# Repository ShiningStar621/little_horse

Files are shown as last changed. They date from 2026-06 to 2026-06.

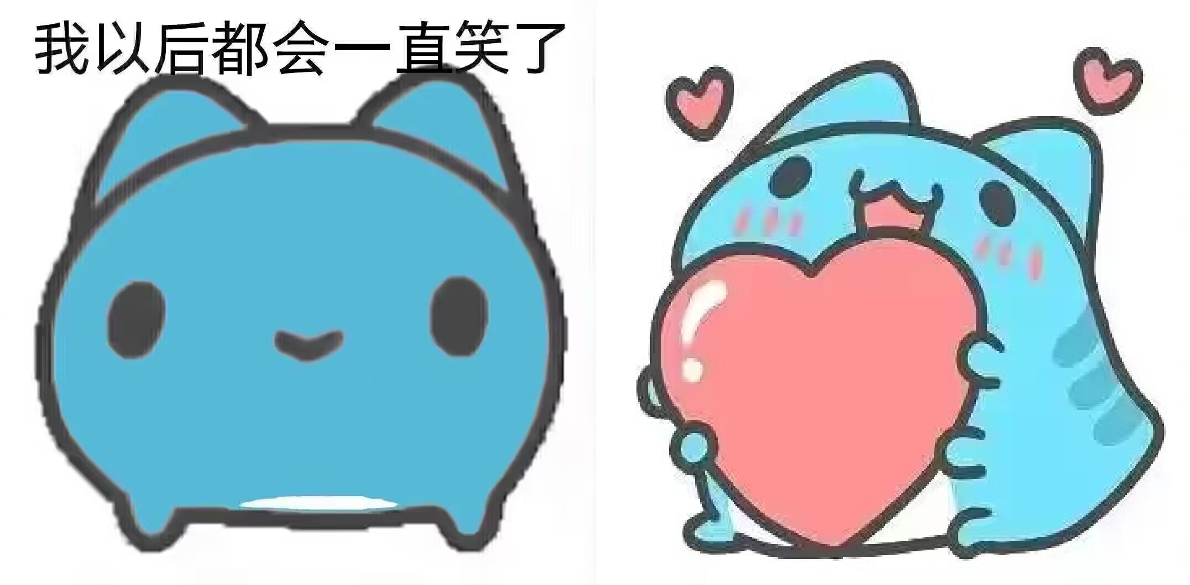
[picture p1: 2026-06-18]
images/原图/EFB1394C15E5EA0CE02DC21B37489DED.jpg

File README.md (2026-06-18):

# 地猛星 (Di Meng Xing) — MSPM0G3507 四足语音机器人

> 哈尔滨工业大学（深圳）电子工艺实习项目  |  2026年4月–6月

基于 TI MSPM0G3507 的四足机器人，集成离线语音识别、OLED 状态显示、MP3 音频
反馈和 4 路舵机步态控制。支持 9 条语音口令非接触控制，5 种步态模式（前进、后退、
左转、右转、跳舞）。

---

## 硬件架构

| 模块 | 型号 | 接口 | 说明 |
|---|---|---|---|
| MCU | MSPM0G3507 (Cortex-M0+, 32MHz) | — | TI LaunchPad 开发板 |
| 语音识别 | CI1302 | 软件 I2C (PB2/PB3) | 离线非特定人，9条口令 |
| 显示屏 | SH1106 OLED 1.3" 128×64 | 软件 SPI (PA12/13/16/17/22) | 单色，页寻址 |
| MP3 播放 | WT2003H4 M09 | UART1 (PA8, 115200) | TF卡，3W功放 |
| 舵机 ×4 | SG90 | 独立 PWM 50Hz | 外部 5V/3A 供电 |
| 3D 外壳 | PLA 打印 | — | 立式屏幕支架+紧凑布局 |

## 引脚映射

| 引脚 | 功能 | 引脚 | 功能 |
|---|---|---|---|
| PA0 | 舵机 FR (前右) | PA15 | 舵机 FL (前左) |
| PA8 | MP3 UART TX | PA16 | OLED DC |
| PA9 | MP3 UART RX | PA17 | OLED RES |
| PA10 | 调试 UART TX | PA21 | 舵机 RL (后左) |
| PA11 | 调试 UART RX | PA22 | OLED CS |
| PA12 | OLED SCL | PA23 | 舵机 RR (后右) |
| PA13 | OLED SDA | PB2 | CI1302 SCL |
| PA14 | 板载 LED | PB3 | CI1302 SDA |

## 语音命令

| 口令 | 命令ID | 步态 | 口令 | 命令ID | 步态 |
|---|---|---|---|---|---|
| 前进 | 0x01 | 对角小跑 | 行走 | 0x06 | 归中站立 |
| 后退 | 0x02 | 后退小跑 | 停止 | 0x07 | 卧倒休眠 |
| 左转 | 0x03 | 原地左旋 | 跳舞 | 0x08 | 四相波浪 |
| 右转 | 0x04 | 原地右旋 | 唱歌 | 0x09 | 仅MP3 |
| 坐下 | 0x05 | 坐下姿态 | | | |

## 目录结构

```
├── README.md                  # 本文件
├── docs/                      # 文档
│   ├── 地猛星机器人发布说明书.md / .docx
│   ├── 硬件安装说明书.md
│   └── 屏幕硬件图.pdf
├── firmware/                  # 源代码
│   ├── empty.c                # 主程序 (~740行)
│   ├── board.c / board.h      # 板级初始化+延时
│   ├── ti_msp_dl_config.c/.h  # SysConfig 生成
│   ├── empty.syscfg           # SysConfig 工程
│   ├── LCD/                   # OLED 驱动
│   │   ├── lcd_init.c/.h      # SH1106 底层
│   │   ├── lcd.c/.h           # 上层绘图
│   │   ├── lcdfont.h          # ASCII 字库
│   │   └── img_*.h (×11)      # Image2Lcd 图片
│   └── keil/                  # Keil 工程
├── hardware/                  # 硬件设计
│   ├── pcb文件.epro           # 立创EDA PCB
│   └── 屏幕尺寸.png
├── model/                     # 3D 打印模型 (SolidWorks)
├── voice-module/              # CI1302 语音模块
│   ├── 固件/
│   ├── 烧录工具/
│   └── 文档
├── mp3-module/                # WT2003H4 MP3 模块
├── images/                    # OLED 图片资源
│   ├── 原图/                  # BMP/PNG 原图
│   └── 取模数组/              # Image2Lcd 生成的 .c
└── tools/                     # 工具
    └── Image2Lcd/             # 图片取模工具
```

## 编译与烧录

- **编译器**: ARMCLANG V6.21 (Keil MDK)
- **工程文件**: `firmware/keil/empty_LP_MSPM0G3507_nortos_keil.uvprojx`
- **Include 路径**: `..` (firmware), `../../..` (SDK根), `../LCD`
- **预编译**: 需禁用 Keil 预编译步骤（SysConfig 权限问题）
- **烧录**: Keil F8 或使用 TI Uniflash

## 注意事项

1. **舵机必须独立供电**（外部 5V/3A），绝不能接板卡 5V 排针
2. SH1106 与 SSD1306 驱动不兼容——列偏移 +2、页寻址、电荷泵 0xAD
3. CI1302 识别结果 ID 为 0x01-0x09（播报编号为 0x81-0x89，两者不同）
4. OLED_Init() 必须在 Servo_Init() 之前（避免 GPIO 干扰 PWM）
5. MP3 模块 UART 需手动设 115200（SysConfig 默认 9600）

## 已知问题

- [ ] 前进/后退步态需上机调参以获得地面推力
- [ ] 跳舞/左转/右转步态未经实物验证
- [ ] img_sleep/dance/sing.h 为全黑占位图，待替换
- [ ] SMOOTH_STEP=30 偏大，建议降至 3~10

## 许可

MIT License

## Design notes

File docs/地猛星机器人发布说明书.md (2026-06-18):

# 地猛星 MSPM0G3507 四足机器人 — 发布说明书

> **版本**: 2026-06-16 | **作者**: 地猛星项目组 | **MCU**: MSPM0G3507 (Cortex-M0+, 32MHz)

---

## 一、项目概览

地猛星是一台基于 TI MSPM0G3507 的四足机器人，集成语音识别、OLED 显示、MP3 音频和舵机步态控制。

**核心功能**:
- 语音命令识别（CI1302 离线语音模块，无需联网）
- 1.3 寸 OLED 实时状态显示
- WT2003H4 MP3 模块音频反馈
- 4 路独立 PWM 舵机，非阻塞步态引擎
- 8 种机器人行为：前进/后退/左转/右转/坐下/站立/停止/跳舞/唱歌

---

## 二、硬件架构

### 2.1 MCU — MSPM0G3507

| 项目 | 参数 |
|---|---|
| 内核 | ARM Cortex-M0+ |
| 主频 | 32 MHz |
| Flash | 128 KB |
| SRAM | 32 KB |
| 开发板 | LP-MSPM0G3507 |
| SDK 版本 | mspm0_sdk_1_30_00_03 |
| 编译工具 | Keil MDK V6.21 (ARMCLANG) |

### 2.2 外设模块

| 模块 | 型号 | 通信接口 | 供电 |
|---|---|---|---|
| 语音识别 | CI1302 | I2C (软件模拟, PB2/PB3) | 3.3V |
| OLED 屏幕 | 1.3寸 SH1106 单色 128×64 | SPI (软件模拟) | 3.3V |
| MP3 播放 | WT2003H4 M09 | UART1 (PA8/PA9, 115200) | 5V 外部 |
| 舵机 ×4 | SG90 兼容 | PWM 独立 4 通道 | 5V 外部独立供电 |
| 调试串口 | USB-TTL | UART0 (PA10/PA11, 115200) | USB |

### 2.3 完整引脚映射

| MSPM0 引脚 | 连接对象 | 功能 | 备注 |
|---|---|---|---|
| **PA0** | 舵机 FR | PWM_2 (TIMA0 CCP0) | 前右腿 |
| **PA8** | MP3 模块 RX | UART1 TX | MCU → MP3 |
| **PA9** | MP3 模块 TX | UART1 RX | MP3 → MCU (可选不接) |
| **PA10** | USB-TTL RX | UART0 TX | 调试 printf |
| **PA11** | USB-TTL TX | UART0 RX | 调试输入 |
| **PA12** | OLED D0 | SPI SCL (软件) | 时钟 |
| **PA13** | OLED D1 | SPI SDA (软件) | 数据 |
| **PA14** | 板载 LED | GPIO 输出 | 状态指示 (低电平亮) |
| **PA15** | 舵机 FL | PWM_1 (TIMA1 CCP0) | 前左腿 |
| **PA16** | OLED DC | GPIO 输出 | 命令/数据选择 |
| **PA17** | OLED RES | GPIO 输出 | 复位 |
| **PA21** | 舵机 RL | PWM_3 (TIMG6 CCP0) | 后左腿 |
| **PA22** | OLED CS | GPIO 输出 | 片选 |
| **PA23** | 舵机 RR | PWM_4 (TIMG0 CCP0) | 后右腿 |
| **PB2** | CI1302 SCL | I2C SCL (软件) | 语音模块时钟 |
| **PB3** | CI1302 SDA | I2C SDA (软件) | 语音模块数据 |

### 2.4 电源分配

```
外部 5V 电源 (独立供电，≥2A)
    ├── 舵机 VCC ×4  ⚠️ 必须独立供电
    ├── MP3 模块 VCC
    └── 【不要接板卡 5V 排针！会倒灌烧毁电源】

板卡 3.3V (USB 或板载 LDO)
    ├── OLED VCC
    └── CI1302 VCC

所有模块 GND 必须共地
```

> ⚠️ **舵机必须独立供电**。4 个舵机同时动作峰值电流可达 2-3A，从板卡 5V 取电会导致电压跌落、屏幕掉电重启、MCU 复位等问题。

---

## 三、软件架构

### 3.1 源码结构

```
driverlib/empty/
├── empty.c                    # 【主程序】单文件, ~720行
├── board.c / board.h          # 板级初始化 + delay_us/ms
├── ti_msp_dl_config.c/.h      # SysConfig 自动生成 (时钟/引脚/PWM/UART)
├── empty.syscfg               # SysConfig 工程配置
├── LCD/
│   ├── lcd_init.c/.h          # OLED 驱动 (SH1106 软件 SPI + 帧缓冲)
│   ├── lcd.c/.h               # 上层绘图 (字符/线条/图片)
│   ├── lcdfont.h              # ASCII 字库 (12/16pt)
│   ├── img_idle.h             # 待机图片 (128×64 单色)
│   ├── img_go.h               # 前进图片
│   ├── img_back.h             # 后退图片
│   ├── img_left.h             # 左转图片
│   ├── img_right.h            # 右转图片
│   ├── img_sit.h              # 坐下图片
│   ├── img_walk.h             # 行走图片
│   ├── img_stop.h             # 停止图片
│   ├── img_sleep.h            # 休眠图片
│   ├── img_dance.h            # 跳舞图片
│   └── img_sing.h             # 唱歌图片
└── keil/                      # Keil 工程文件
```

### 3.2 程序执行流程

```
上电
  │
  ├─ board_init()              # 时钟/SysTick/GPIO/UART 初始化
  ├─ MP3_SetVol(25)            # MP3 模块音量初始化
  ├─ MP3_Stop()                # 确保 MP3 停止
  ├─ OLED_Init()               # SH1106 初始化 + 清屏
  ├─ Servo_Init()              # 4 舵机归中 (CCR=750)
  ├─ 开机自检                  # 舵机微动确认 PWM 正常
  └─ 进入主循环 ──────────────┐
        │                      │
        ├─ CI1302_Recognition() # 轮询语音识别结果 (I2C)
        ├─ 如有新命令 → HandleCommand()
        │   ├─ 更新 OLED 图片+文字
        │   ├─ 触发 MP3 播放
        │   ├─ CI1302 语音播报
        │   └─ 设置舵机状态机 (g_state)
        │
        ├─ 非阻塞步态更新 (根据 g_state)
        │   ├─ STATE_WALK_FORWARD  → GAIT_FORWARD
        │   ├─ STATE_WALK_BACKWARD → GAIT_BACKWARD
        │   ├─ STATE_TURN_LEFT     → GAIT_TURN_LEFT
        │   ├─ STATE_TURN_RIGHT    → GAIT_TURN_RIGHT
        │   └─ STATE_DANCE         → GAIT_DANCE
        │
        └─ delay_ms(5) ──────────┘
```

### 3.3 系统状态机

| 状态 | 枚举值 | 触发命令 | 步态行为 |
|---|---|---|---|
| `STATE_IDLE` | 0 | 停止(0x07) | 不更新步态 |
| `STATE_WALK_FORWARD` | 1 | 前进(0x01)/行走(0x06) | 非阻塞前进步态 |
| `STATE_WALK_BACKWARD` | 2 | 后退(0x02) | 非阻塞后退步态 |
| `STATE_TURN_LEFT` | 3 | 左转(0x03) | 非阻塞原地左旋 |
| `STATE_TURN_RIGHT` | 4 | 右转(0x04) | 非阻塞原地右旋 |
| `STATE_SIT` | 5 | 坐下(0x05) | 阻塞: 坐下姿态 |
| `STATE_DANCE` | 6 | 跳舞(0x08) | 非阻塞跳舞步态 |

---

## 四、通信协议

### 4.1 CI1302 语音识别 (I2C)

| 项目 | 参数 |
|---|---|
| 接口 | 软件模拟 I2C (PB2=SCL, PB3=SDA) |
| 从机地址 | 0x34 (7-bit) |
| 识别结果寄存器 | 0x64 |
| 播报命令寄存器 | 0x6E |

**命令 ID 映射** (CI1302 出厂固化的语音词条):

| 语音口令 | 命令 ID | 功能 |
|---|---|---|
| "前进" | 0x01 | 向前走 |
| "后退" | 0x02 | 向后退 |
| "左转" | 0x03 | 原地左旋 |
| "右转" | 0x04 | 原地右旋 |
| "坐下" | 0x05 | 坐下姿态 |
| "行走" | 0x06 | 向前走 (同前进) |
| "停止" | 0x07 | 卧倒休眠 |
| "跳舞" | 0x08 | 跳舞步态 |
| "唱歌" | 0x09 | MP3 唱歌 |

**播报触发**:
```c
CI1302_Speak(CI1302_CMD, 0x81);     // CI1302 播放预存语音 0x81
CI1302_Speak(CI1302_ANNOUNCE, 0x01); // 开机播报
```

### 4.2 WT2003H4 MP3 (UART)

| 项目 | 参数 |
|---|---|
| 接口 | UART1 (PA8=TX, PA9=RX) |
| 波特率 | 115200 bps |
| 协议 | 二进制帧: `7E + 长度 + 命令 + 参数 + 校验和 + EF` |

**常用命令**:
```c
MP3_Play(n)   // 播放第 n 首 (索引模式: 0xA0 + 2字节索引)
MP3_Stop()    // 停止播放 (0xAB)
MP3_SetVol(v) // 设置音量 0-31 (0xAE)
```

**波特率配置** (UART1 时钟 4MHz → 115200):
```c
DL_UART_Main_setBaudRateDivisor(UART_1_INST, 2, 11);  // DIV=2, MOD=11
```

### 4.3 SH1106 OLED (SPI)

| 项目 | 参数 |
|---|---|
| 分辨率 | 128×64 单色 |
| 接口 | 软件 SPI (PA12=SCL, PA13=SDA) |
| 控制引脚 | PA17=RES, PA16=DC, PA22=CS |
| 缓冲 | OLED_GRAM[128][8] (1024 字节) |
| 寻址 | 页寻址模式 (SH1106 不支持水平寻址) |

**图片格式**: Image2Lcd 取模, 水平扫描, 单色, 6 字节头 `[scan][bpp][w_lo][w_hi][h_lo][h_hi]`

---

## 五、舵机系统

### 5.1 PWM 配置

| 参数 | 值 | 说明 |
|---|-----|---|
| PWM 频率 | 50 Hz | 标准舵机频率 |
| 定时器时钟 | 500 kHz | 预分频后 |
| PWM 周期 (ARR) | 10000 | 20ms 周期 |
| CCR 范围 | 250 ~ 1250 | 0.5ms ~ 2.5ms 脉宽 |
| 中立位 CCR | 750 | 1.5ms 脉宽 = 90° |
| CCR ↔ 角度 | `CCR = 250 + angle × 1000 / 180` | 线性映射 |

### 5.2 舵机映射与安装方向

| 通道 | 腿 | PWM 实例 | MCU 引脚 | 安装方向 | g_legInv |
|---|-----|---|---|---|---|
| ch0 | FL 前左 | PWM_1 (TIMA1) | PA15 | 齿轮朝前 (正常) | 0 |
| ch1 | FR 前右 | PWM_2 (TIMA0) | PA0 | 齿轮朝前 (正常) | 1 |
| ch2 | RL 后左 | PWM_3 (TIMG6) | PA21 | 齿轮朝后 (反装) | 0 |
| ch3 | RR 后右 | PWM_4 (TIMG0) | PA23 | 齿轮朝后 (反装) | 1 |

**反相逻辑** (`g_legInv`):
- `inv=0` (正常): `CCR = v` — 直接使用步态曲线值
- `inv=1` (反相): `CCR = 1500 - v` — 绕中立位 750 镜像

> **为什么需要反相**: FR (前右) 和 RR (后右) 的舵机齿轮朝向与其他腿不同，相同 CCR 值会导致物理运动方向相反。反相后四条腿的物理运动方向统一。

### 5.3 特殊姿态

| 姿态 | FL (ch0) | FR (ch1) | RL (ch2) | RR (ch3) |
|---|---|---|---|---|
| 中立 (归中) | 750 | 750 | 750 | 750 |
| 坐下 | 750 | 750 | 1250 | 250 |
| 卧倒休眠 | 250 | 1250 | 1250 | 250 |

---

## 六、步态引擎

### 6.1 核心参数

```c
#define CYCLE_STEPS     100    // 周期步数 (100步 × 5ms = 500ms/周期)
#define CYCLE_DELAY_MS  5      // 每步延时
#define SMOOTH_STEP     30     // 每步 CCR 逼近量 (越大响应越快)
#define LAG_STEPS       (CYCLE_STEPS / 2)  // 对角腿相位差 (50步 = 半周期)
```

### 6.2 步态曲线

**前进曲线** `Gait_ForwardCCR(t)`:
- 0~9 步 (10%): 快前摆 — CCR 1050→450 (向前快速摆动)
- 10~99 步 (90%): 慢后推 — CCR 450→990 (向后慢速蹬地)

**后退曲线** `Gait_BackwardCCR(t)`:
- 0~9 步 (10%): 快后摆 — CCR 450→1050
- 10~99 步 (90%): 慢前推 — CCR 1050→510

> **设计原理**: 不对称占空比 (10% 摆动 + 90% 蹬地) 模拟生物步态。快速前摆减少空气阻力时间，慢速蹬地提供推进力。

### 6.3 步态模式

| 步态 | 对角配对 | 描述 |
|---|---|---|
| **前进** | FL+RR 领先 / FR+RL 滞后 | 对角小跑 (trot)，对角线两条腿同步 |
| **后退** | FL+RR 领先 / FR+RL 滞后 | 后退对角小跑 |
| **左转** | FL 后退+FR 前进 / RL 后退+RR 前进 | 右侧前进+左侧后退 = 原地逆时针旋转 |
| **右转** | FL 前进+FR 后退 / RL 前进+RR 后退 | 左侧前进+右侧后退 = 原地顺时针旋转 |
| **跳舞** | FL→FR→RL→RR 依次 1/4 周期 | 四相波浪传播，前后腿反相摇摆 |

### 6.4 平滑逼近算法

所有非阻塞步态使用相同的平滑插值:
```c
if (cur < target) cur += SMOOTH_STEP;  // 逐步接近目标
if (cur > target) cur -= SMOOTH_STEP;
```
这避免了瞬时 CCR 跳变导致的舵机剧烈抖动。

---

## 七、编译与烧录

### 7.1 Keil 工程

| 项目 | 路径/值 |
|---|---|
| 工程文件 | `keil/empty_LP_MSPM0G3507_nortos_keil.uvprojx` |
| 编译器 | ARMCLANG V6.21 |
| 优化等级 | -O0 (调试) |
| 代码大小 | ~14 KB Flash |
| 预编译步骤 | SysConfig 自动生成 `ti_msp_dl_config.c/.h` |

### 7.2 编译步骤

1. 打开 Keil 工程
2. 确认 `Options → C/C++ → Include Paths` 包含:
   - `..` (empty 目录)
   - `../../..` (SDK 根目录)
   - `../LCD`
3. Rebuild (F7)
4. 确认 0 Errors, 0 Warnings
5. 烧录 (F8)

### 7.3 首次上电检查

1. USB-TTL 接 PA10/PA11, 115200bps, 应看到:
   ```
   ================================
    DMX + CI1302 + OLED + Servo
   ================================
   [SERVO] 4ch ready
   [SYS] Ready.
   ```
2. OLED 显示待机画面
3. 舵机短暂微动后归中 (开机自检)
4. 说出语音口令测试各项功能

---

## 八、语音命令速查表

| 口令 | 命令ID | OLED 显示 | 舵机动作 | MP3 |
|---|---|---|---|-----|
| "前进" | 0x01 | 前进图标 | 连续前进 (对角小跑) | 第1首 |
| "后退" | 0x02 | 后退图标 | 连续后退 | 第2首 |
| "左转" | 0x03 | 左转图标 | 持续原地左旋 | 第3首 |
| "右转" | 0x04 | 右转图标 | 持续原地右旋 | 第4首 |
| "坐下" | 0x05 | 坐下图标 | 前腿归中 + 后腿前弯90° | - |
| "行走" | 0x06 | 行走图标 | 归中 (站立) | - |
| "停止" | 0x07 | 休眠图标 | 归中 → 200秒后卧倒休眠 | 第2首 |
| "跳舞" | 0x08 | 跳舞图标 | 连续四相波浪步态 | - |
| "唱歌" | 0x09 | 唱歌图标 | 不动 | 第1首 |

---

## 九、已知问题与解决记录

### 9.1 已解决

| 问题 | 原因 | 解决方案 |
|---|---|---|
| OLED 不亮 | 代码为 ST7789 TFT 驱动 | 重写 SH1106 初始化序列 + 页寻址 |
| OLED 显示花屏 | SH1106 不支持水平寻址 | 改用页寻址模式 `OLED_Refresh()` |
| 舵机不动 | CCR 范围错误 (0-3750) | 修正为 250-1250 (对应 0.5-2.5ms) |
| 代码超 32KB | Keil 评估版限制 | 禁用中文字库和大号 ASCII 字库 |
| 后腿运动方向错误 | 齿轮朝后安装 | 添加 `g_legInv[4]` 反相标志 |
| 跳舞时后腿不动 | `90 - Gait_ForwardCCR()` 负值溢出 | 改用四相波浪步态，正确使用 g_legInv |
| 闪屏/重复刷新 | 防抖逻辑缺失 | 添加 `g_lastDisplayedCmd` 缓存 |
| 编译报错 EPERM | syscfg.bat 权限问题 | 禁用预编译步骤 |
| 编译报错未声明 | 图片头文件缺失 | 创建 img_sleep/dance/sing.h 占位 |
| 停止命令误触 | 舵机直接归中不自然 | 改为先归中→延时→卧倒休眠姿态 |
| 编译 include 路径冲突 | 同名 board.h 被错误引用 | 清理重复路径 |

### 9.2 待优化

| 问题 | 状态 | 建议 |
|---|---|---|
| 行走不能实际前进 | 参数需调试 | 调整步态曲线、LAG_STEPS、CYCLE_STEPS |
| 跳舞步态未经实测 | 新改 | 需上机验证 |
| 左转/右转未经实测 | 新改 | 需上机验证 |
| 图片为全黑占位 | 待替换 | 用 Image2Lcd 取模实际图片 |
| SMOOTH_STEP=30 可能过大 | 待调试 | 过大=接近无平滑, 过小=响应慢 |

---

## 十、附录

### A. MP3 模块 TF 卡文件命名

文件放在 TF 卡根目录，命名为 `001xxx.mp3`, `002xxx.mp3`... 与 `MP3_Play(n)` 的索引对应。

| MP3_Play(n) | 建议曲目 |
|---|---|
| 1 | 前进/唱歌 音效 |
| 2 | 后退/停止 音效 |
| 3 | 左转 音效 |
| 4 | 右转 音效 |
| 5 | 坐下 音效 |
| 6 | 行走 音效 |
| 7 | 跳舞 音效 |
| 8 | 唱歌 音乐 |

### B. OLED 图片制作 (Image2Lcd)

1. 准备 128×64 像素或更小的黑白图片 (BMP/PNG)
2. 打开 Image2Lcd → 导入图片
3. 设置: **水平扫描, 单色, 不压缩**
4. 生成 C 数组 → 替换 `LCD/img_*.h` 中的数组内容
5. 数组名必须与 include 的变量名一致 (如 `gImage_sleep`)

### C. SH1106 与 SSD1306 关键差异

| 项目 | SSD1306 | SH1106 |
|---|---|---|
| 列起始地址 | 0 | 2 (需 +2 偏移) |
| 水平寻址 | 支持 | **不支持** |
| 页寻址 | 支持 | 支持 (本项目使用) |
| 电荷泵寄存器 | 0x8D | 0xAD |
| 最大列数 | 128 | 132 |

### D. 调试串口命令

连接 PA10/PA11 (115200bps)，可观察:
- `[CMD] 0xXX <命令名>` — 每次语音识别结果
- `[DBG] g_state=X` — 当前状态机状态 (如开启)
- 舵机 CCR 值 (可取消注释 `printf("[DBG]...")` 观察)

### E. 项目历史版本

| 版本 | 屏幕方案 | 说明 |
|---|---|---|
| V1 (empty.txt) | TJC 串口屏 方案A (切页) | 已验证正常 |
| V2 (empty.c 旧) | TJC 串口屏 方案B (控件) | 闪屏问题已修复 |
| V3 (main.c) | TJC 串口屏 模块化 | 命令ID 错误 (0x01 vs 0x81) |
| **V4 (当前)** | **SH1106 OLED** | **当前发布版本** |

---

> **文档维护**: 硬件接线变更、新增语音口令、步态参数调整后需同步更新本文档。

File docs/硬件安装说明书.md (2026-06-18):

# 地猛星 MSPM0G3507 机器人 硬件安装说明书

## 一、引脚总表

### MCU → 外设 一览

| MSPM0 引脚 | 连接对象 | 功能 | 备注 |
|---|---|---|---|
| PA0 | 舵机 | PWM_2 前右腿 (FR) | |
| PA10 | 串口模块 | UART0 TX 调试输出 | 115200bps |
| PA11 | 串口模块 | UART0 RX | |
| PA12 | OLED D0 | SPI 时钟 SCL | |
| PA13 | OLED D1 | SPI 数据 SDA | |
| PA14 | 板载 LED | 状态指示 | |
| PA15 | 舵机 | PWM_1 前左腿 (FL) | |
| PA16 | OLED DC | 命令/数据选择 | |
| PA17 | OLED RES | 复位 | |
| PA21 | 舵机 | PWM_3 后左腿 (RL) | |
| PA22 | OLED CS | 片选 | |
| PA23 | 舵机 | PWM_4 后右腿 (RR) | |
| PA8 | MP3 模块 RX | UART1 TX (发数据给MP3) | |
| PB2 | CI1302 SCL | I2C 时钟 | 语音识别 |
| PB3 | CI1302 SDA | I2C 数据 | 语音识别 |

---

## 二、各模块接线详图

### 1. OLED 屏幕 (1.3寸 SH1106, 7针)

```
OLED 引脚          MSPM0 引脚
────────────────────────────
GND      ────     GND
VCC      ────     3.3V
D0(SCL)  ────     PA12
D1(SDA)  ────     PA13
RES      ────     PA17
DC       ────     PA16
CS       ────     PA22
```

### 2. CI1302 语音识别模块 (I2C)

```
CI1302             MSPM0 引脚
────────────────────────────
GND      ────     GND
3.3V     ────     3.3V
SCL      ────     PB2
SDA      ────     PB3
```

### 3. 舵机 (4路)

```
舵机               MSPM0 引脚    通道
───────────────────────────────────
前左腿 FL 信号 ──  PA15         PWM_1
前右腿 FR 信号 ──  PA0          PWM_2
后左腿 RL 信号 ──  PA21         PWM_3
后右腿 RR 信号 ──  PA23         PWM_4
所有舵机 VCC ────  外部 5V 电源  (独立供电!)
所有舵机 GND ────  外部电源 GND + 板卡 GND (共地)
```

> ⚠️ 舵机必须**独立供电**（外部 5V），不要从板卡 5V 取电。

### 4. MP3 模块 (WT2003H4 M09)

```
MP3 模块           连接
────────────────────────────
VCC      ────     外部 5V 电源
GND      ────     外部电源 GND + 板卡 GND
RX       ────     PA8 (MSPM0 TX)
TX       ────     不接 (可选)
```

---

## 三、电源分配

```
外部 5V 电源
    ├── 舵机 VCC (4路)
    ├── MP3 模块 VCC
    └── (不要接板卡 5V 排针)

板卡 3.3V
    ├── OLED VCC
    ├── CI1302 VCC
    └── 其他 3.3V 外设

所有模块 GND 必须共地
```

---

## 四、首次上电检查

1. 万用表量 OLED VCC-GND 间电压 = 3.3V
2. 万用表量 MP3 模块 VCC-GND 间电压 = 5V
3. 串口助手 115200bps 应看到 `Board Init...` 开机信息
4. OLED 应显示 "DMX Robot" + "Ready..."
5. 舵机短暂微动自检

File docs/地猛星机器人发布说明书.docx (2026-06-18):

# Di Meng Xing MSPM0G3507 Quadruped Robot - Release Manual

Version: 2026-06-16 | MCU: MSPM0G3507 (Cortex-M0+, 32MHz) | SDK: mspm0_sdk_1_30_00_03

# 1. Project Overview

Di Meng Xing is a quadruped robot based on TI MSPM0G3507, integrating voice recognition, OLED display, MP3 audio and servo gait control.

## Core Features

- Voice command recognition (CI1302 offline module, no network required)
- 1.3-inch SH1106 OLED real-time status (128x64 monochrome)
- WT2003H4 M09 MP3 module audio feedback
- 4-channel independent PWM servo (SG90-compatible), non-blocking gait engine
- 9 robot behaviors: Forward / Backward / Left Turn / Right Turn / Sit / Stand / Stop(Sleep) / Dance / Sing

# 2. Hardware Architecture

## 2.1 Core MCU - MSPM0G3507

Item | Specification
Core | ARM Cortex-M0+
Frequency | 32 MHz
Flash / SRAM | 128 KB / 32 KB
Dev Board | LP-MSPM0G3507
SDK | mspm0_sdk_1_30_00_03
Toolchain | Keil MDK V6.21 (ARMCLANG)

## 2.2 Peripheral Modules

Module | Model | Interface | Power
Voice Recognition | CI1302 | I2C bit-bang (PB2/PB3) | 3.3V
OLED Display | 1.3" SH1106 128x64 | SPI bit-bang (PA12/13/16/17/22) | 3.3V
MP3 Player | WT2003H4 M09 | UART1 (PA8/PA9, 115200) | External 5V
Servo x4 | SG90 Compatible | Independent PWM x4 | External 5V
Debug UART | USB-TTL | UART0 (PA10/PA11, 115200) | USB

## 2.3 Complete Pin Map

MSPM0 Pin | Connected To | Function | Notes
PA0 | Servo FR | PWM_2 (TIMA0 CCP0) | Front Right leg
PA8 | MP3 Module RX | UART1 TX | MCU -> MP3
PA9 | MP3 Module TX | UART1 RX | MP3 -> MCU (optional)
PA10 | USB-TTL RX | UART0 TX | Debug printf output
PA11 | USB-TTL TX | UART0 RX | Debug input
PA12 | OLED D0 | SPI SCL (bit-bang) | Clock
PA13 | OLED D1 | SPI SDA (bit-bang) | Data
PA14 | On-board LED | GPIO Output | Status indicator (active low)
PA15 | Servo FL | PWM_1 (TIMA1 CCP0) | Front Left leg
PA16 | OLED DC | GPIO Output | Command/Data select
PA17 | OLED RES | GPIO Output | Reset
PA21 | Servo RL | PWM_3 (TIMG6 CCP0) | Rear Left leg
PA22 | OLED CS | GPIO Output | Chip Select
PA23 | Servo RR | PWM_4 (TIMG0 CCP0) | Rear Right leg
PB2 | CI1302 SCL | I2C SCL (bit-bang) | Voice module clock
PB3 | CI1302 SDA | I2C SDA (bit-bang) | Voice module data

## 2.4 Power Distribution

External 5V (independent, >= 2A)
+-- Servo VCC x4 <-- MUST use independent power!
+-- MP3 Module VCC
+-- DO NOT connect to board 5V pin! (will backfeed and damage PSU)

Board 3.3V (USB or on-board LDO)
+-- OLED VCC
+-- CI1302 VCC

ALL modules GND must share common ground.

!! Servos MUST use independent power. 4 servos peak ~2-3A. Drawing from board 5V causes voltage sag, screen brownout, and MCU reset.

# 3. Software Architecture

## 3.1 Source Tree

driverlib/empty/
+-- empty.c # Main program (single-file, ~720 lines)
+-- board.c / board.h # Board init + delay_us/ms
+-- ti_msp_dl_config.c/.h # SysConfig auto-generated
+-- empty.syscfg # SysConfig project config
+-- LCD/
+-- lcd_init.c/.h # OLED driver (SH1106 SPI + framebuffer)
+-- lcd.c/.h # Draw primitives (char/line/image)
+-- lcdfont.h # ASCII fonts (12/16pt)
+-- img_idle.h # Idle image
+-- img_go.h / img_back.h # Forward/Backward
+-- img_left.h / img_right.h # Left/Right turn
+-- img_sit.h / img_walk.h # Sit/Walk
+-- img_sleep.h / img_stop.h # Sleep/Stop
+-- img_dance.h / img_sing.h # Dance/Sing
+-- keil/ # Keil project files

## 3.2 Startup Flow

Power On
+-- board_init() # Clocks / SysTick / GPIO / UART
+-- MP3_SetVol(25) # MP3 volume 25/31
+-- MP3_Stop() # Ensure MP3 stopped
+-- OLED_Init() # SH1106 init + clear screen
+-- Servo_Init() # 4 servos to mid (CCR=750)
+-- Self-test # Servo wiggle to confirm PWM OK
+-- Main Loop ---------------+
+-- CI1302_Recognition() # Poll voice result
+-- New cmd -> HandleCommand()
| +-- Update OLED
| +-- Trigger MP3
| +-- CI1302 speak
| +-- Set state (g_state)
+-- Non-blocking gait update (per g_state)
+-- delay_ms(5) -------+

## 3.3 State Machine

State | Enum | Trigger (cmd ID) | Gait Behavior
STATE_IDLE | 0 | 0x07 Stop | No gait update
STATE_WALK_FORWARD | 1 | 0x01 / 0x06 | Non-blocking forward trot
STATE_WALK_BACKWARD | 2 | 0x02 | Non-blocking backward trot
STATE_TURN_LEFT | 3 | 0x03 | Non-blocking left pivot
STATE_TURN_RIGHT | 4 | 0x04 | Non-blocking right pivot
STATE_SIT | 5 | 0x05 | Blocking: sit pose
STATE_DANCE | 6 | 0x08 | Non-blocking 4-phase wave

# 4. Communication Protocols

## 4.1 CI1302 Voice Recognition (I2C)

Item | Value
Interface | Bit-bang I2C (PB2=SCL, PB3=SDA)
Slave Address | 0x34 (7-bit)
Result Register | 0x64
Speak Cmd Register | 0x6E

Voice Command ID Map:

Voice Command | Cmd ID | Function
"Forward" | 0x01 | Walk forward
"Backward" | 0x02 | Walk backward
"Left turn" | 0x03 | Pivot left
"Right turn" | 0x04 | Pivot right
"Sit" | 0x05 | Sit pose
"Walk" | 0x06 | Walk forward (same as 0x01)
"Stop" | 0x07 | Sleep pose
"Dance" | 0x08 | Dance gait
"Sing" | 0x09 | MP3 sing only

## 4.2 WT2003H4 MP3 (UART)

Item | Value
Interface | UART1 (PA8=TX, PA9=RX)
Baud Rate | 115200 bps
Protocol | Binary: 7E + len + cmd + params + checksum + EF

Key Macros:

MP3_Play(n) // Play track N (0xA0 cmd + 2-byte index)
MP3_Stop() // Stop playback (0xAB cmd)
MP3_SetVol(v) // Volume 0-31 (0xAE cmd)

// Baud config: UART1 4MHz -> 115200
DL_UART_Main_setBaudRateDivisor(UART_1_INST, 2, 11);

## 4.3 SH1106 OLED (SPI)

Item | Value
Resolution | 128x64 monochrome
SPI Pins | PA12=SCL, PA13=SDA (bit-bang)
Control Pins | PA17=RES, PA16=DC, PA22=CS
Framebuffer | OLED_GRAM[128][8] (1024 bytes)
Addressing | Page mode (SH1106 no horizontal)
Image Format | Image2Lcd: horiz scan, mono, 6-byte header

# 5. Servo System

## 5.1 PWM Parameters

Parameter | Value | Description
PWM Frequency | 50 Hz | Standard servo frequency
Timer Clock | 500 kHz | After prescaler
PWM Period (ARR) | 10000 | 20ms period
CCR Range | 250 ~ 1250 | 0.5ms ~ 2.5ms pulse width
Neutral CCR | 750 | 1.5ms pulse = 90 degrees
CCR <-> Angle | CCR = 250 + angle * 1000 / 180 | Linear mapping

## 5.2 Servo Mapping & Mount Direction

Ch | Leg | PWM Instance | MCU Pin | Mount | g_legInv
ch0 | FL (Front Left) | PWM_1 (TIMA1) | PA15 | Gear forward (normal) | 0
ch1 | FR (Front Right) | PWM_2 (TIMA0) | PA0 | Gear forward (normal) | 1
ch2 | RL (Rear Left) | PWM_3 (TIMG6) | PA21 | Gear backward (flipped) | 0
ch3 | RR (Rear Right) | PWM_4 (TIMG0) | PA23 | Gear backward (flipped) | 1

Inversion Logic (g_legInv):

inv=0 (normal): CCR = v // direct gait curve value
inv=1 (inverted): CCR = 1500 - v // mirrored around neutral 750

FR and RR have their servo gears facing opposite to the other legs. Same CCR value would produce opposite physical motion. Inversion unifies the physical direction across all 4 legs.

## 5.3 Special Pose Reference

Pose | FL (ch0) | FR (ch1) | RL (ch2) | RR (ch3)
Neutral (stand) | 750 | 750 | 750 | 750
Sit | 750 | 750 | 1250 | 250
Sleep (lie down) | 250 | 1250 | 1250 | 250

# 6. Gait Engine

## 6.1 Core Parameters

#define CYCLE_STEPS 100 // Steps per cycle (100 x 5ms = 500ms/cycle)
#define CYCLE_DELAY_MS 5 // Main loop delay (ms)
#define SMOOTH_STEP 30 // CCR approach per step (higher = faster)
#define LAG_STEPS (CYCLE_STEPS / 2) // Diagonal leg phase offset = 50 steps = half-cycle

## 6.2 Gait Curve Formulas

Forward Curve Gait_ForwardCCR(t):

t %= 100;
if (t < 10)
return 1050 - t * 60; // 10%: fast forward swing (1050->450)
else
return 450 + (t-10) * 6; // 90%: slow backward push (450->990)

Backward Curve Gait_BackwardCCR(t):

t %= 100;
if (t < 10)
return 450 + t * 60; // 10%: fast backward swing (450->1050)
else
return 1050 - (t-10) * 6;// 90%: slow forward push (1050->510)

Design: Asymmetric duty cycle (10% fast swing + 90% slow push) mimics biological gait. Fast swing minimizes air time; slow push provides sustained thrust.

## 6.3 Five Gait Modes

Gait Mode | Diagonal Pairing | Description
Forward GAIT_FORWARD | FL+RR lead / FR+RL lag (half-cycle) | Diagonal trot, diagonal legs move together
Backward GAIT_BACKWARD | FL+RR lead / FR+RL lag (half-cycle) | Reverse diagonal trot
Left Turn GAIT_TURN_LEFT | FL+RL backward / FR+RR forward | Right pushes forward + left backward = CCW rotation
Right Turn GAIT_TURN_RIGHT | FL+RL forward / FR+RR backward | Left pushes forward + right backward = CW rotation
Dance GAIT_DANCE | FL->FR->RL->RR each 1/4 cycle apart | 4-phase wave + front/rear phase inversion

## 6.4 Smooth Interpolation

All non-blocking gaits use the same interpolation to avoid servo jitter from instant CCR jumps:

for (int ch = 0; ch < 4; ch++) {
uint16_t cur = g_servoCCR[ch];
if (cur < target[ch]) { cur += SMOOTH_STEP; if (cur > target[ch]) cur = target[ch]; }
else if (cur > target[ch]) { cur -= SMOOTH_STEP; if (cur < target[ch]) cur = target[ch]; }
g_servoCCR[ch] = cur;
Servo_WriteCCR(ch, cur);
}

# 7. Build & Flash

## 7.1 Project Configuration

Item | Value
Project File | keil/empty_LP_MSPM0G3507_nortos_keil.uvprojx
Compiler | ARMCLANG V6.21
Optimization | -O0 (debug)
Code Size | ~14 KB Flash
Pre-build | SysConfig auto-generates ti_msp_dl_config.c/.h

## 7.2 Include Paths

.. # empty directory
..\..\.. # SDK root
..\LCD # OLED driver + images

## 7.3 First Power-On Checklist

- USB-TTL connected to PA10/PA11, 115200bps. Should see boot banner and [SYS] Ready.
- OLED shows idle image (gImage_idle).
- Servos briefly wiggle then return to neutral (self-test).
- Speak "Forward" / "Backward" etc. to test each function.

# 8. Voice Command Quick Reference

Command | ID | OLED | Servo Action | MP3
"Forward" | 0x01 | Forward icon | Continuous forward trot | Track 1
"Backward" | 0x02 | Backward icon | Continuous backward trot | Track 2
"Left turn" | 0x03 | Left icon | Continuous left pivot | Track 3
"Right turn" | 0x04 | Right icon | Continuous right pivot | Track 4
"Sit" | 0x05 | Sit icon | Front legs neutral + rear fold 90 deg | -
"Walk" | 0x06 | Walk icon | Return to neutral (stand) | -
"Stop" | 0x07 | Sleep icon | Neutral -> delay -> sleep pose | Track 2
"Dance" | 0x08 | Dance icon | Continuous 4-phase wave | -
"Sing" | 0x09 | Sing icon | No movement (audio only) | Track 1

# 9. Known Issues & Resolution Log

## Resolved (11 items)

Issue | Root Cause | Solution
OLED no display | Code was for ST7789 TFT | Rewrote SH1106 init + page addressing
OLED garbled | SH1106 lacks horizontal addressing | Use page addressing in OLED_Refresh()
Servo not moving | Wrong CCR range 0-3750 | Corrected to 250-1250 (0.5-2.5ms)
Code >32KB | Keil eval limit | Disabled Chinese fonts + large ASCII
Rear legs wrong direction | Gear mounted backward | Added g_legInv[4] inversion flags
Dance: rear legs stuck | 90-CCR() = negative overflow | 4-phase wave + g_legInv fix
Screen flicker | Missing debounce | Added g_lastDisplayedCmd cache
EPERM build error | syscfg.bat permission | Disabled pre-build step
Undeclared identifier | Missing img_sleep/dance/sing.h | Created placeholder image headers
Stop action unnatural | Direct servo center | Center -> delay -> sleep pose
Include path conflict | Duplicate board.h | Cleaned redundant paths

## Pending (5 items)

Issue | Status | Suggestion
Forward walking not actually moving | Needs tuning | Adjust gait curve, LAG_STEPS, CYCLE_STEPS
Dance gait | New, untested | Needs hardware verification
Left/Right turn | New, untested | Needs hardware verification
OLED images are blank | Placeholders | Use Image2Lcd to generate real images
SMOOTH_STEP=30 too large | May skip smoothing | Try 3-10 for smoother motion

# 10. Appendix

## A. MP3 TF Card File Naming

Place files in TF card root. Name as 001xxx.mp3 ~ 008xxx.mp3, corresponding to MP3_Play(n):

MP3_Play(n) | Suggested Track
1 | Forward / Sing sound
2 | Backward / Stop sound
3 | Left turn sound
4 | Right turn sound
5 | Sit sound
6 | Walk sound
7 | Dance music
8 | Sing music

## B. OLED Image Creation (Image2Lcd)

- Prepare 128x64 or smaller B/W image (BMP/PNG)
- Open Image2Lcd -> Import image
- Settings: Horizontal scan, Monochrome, No compression
- Generate C array -> Replace array content in LCD/img_*.h
- Array name must match the include variable name (e.g. gImage_sleep)

## C. SH1106 vs SSD1306 Key Differences

Item | SSD1306 | SH1106 (This Project)
Column start | 0 | 2 (need +2 offset)
Horizontal addressing | Supported | NOT supported
Page addressing | Supported | Supported (used here)
Charge pump register | 0x8D | 0xAD
Max columns | 128 | 132

## D. Debug Serial

Connect PA10/PA11 (115200bps). Observable output:

- [CMD] 0xXX <Name> - Each voice recognition result
- [DBG] g_state=X - Current state machine state
- Servo CCR values (uncomment printf to observe)

## E. Project Version History

Version | Display | Notes
V1 (empty.txt) | TJC serial screen Plan A (page switch) | Verified working
V2 (empty.c old) | TJC serial screen Plan B (widget update) | Flicker fixed
V3 (main.c) | TJC serial screen, modularized | Wrong cmd IDs (0x01 vs 0x81)
V4 (current) | SH1106 OLED monochrome | Current release version

- End of Document -

Update this document when hardware wiring, voice commands, or gait parameters change.

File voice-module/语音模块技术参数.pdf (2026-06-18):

# 一体式语音交互模块技术参数

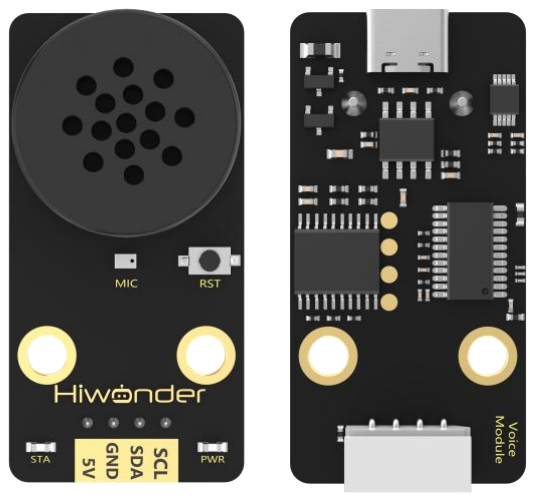
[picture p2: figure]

产品尺寸 | 48*24*10.5mm | 产品重量 | 10g
语音芯片型号 | CI1302 | IIC 接口 | 1 个
Type-C 串口 | 1 个 | 工作电压 | 5V
CPU 主频 | 可达 220MHz | RAM 容量 | 640KByte
FLASH 容量 | 2MByte | 工作温度 | 常温

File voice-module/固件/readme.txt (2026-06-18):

1. For detailed information about the SDK's components, features, and development, please refer to the SDK documentation for the corresponding chip series in the Software Development section of the Docume
   Taking CI13060 as an example, the reference link is as follows: https://document.chipintelli.com/%E8%BD%AF%E4%BB%B6%E5%BC%80%E5%8F%91/SDK/CI130X%E8%8A%AF%E7%89%87SDK/CI-SDK-Offline/

2. If you need to modify and adjust the relevant algorithm parameters in the SDK, please refer to the SDK documentation for the corresponding chip series in the Software Development section of the Documentation Center.
   Taking AEC as an example, the reference link is as follows:：https://document.chipintelli.com/%E8%BD%AF%E4%BB%B6%E5%BC%80%E5%8F%91/SDK/CI130X%E8%8A%AF%E7%89%87SDK/components/%E5%9B%9E%E5%A3%B0%E6%B6%88%E9%99%A4%E4%BD%BF%E7%94%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

3. If the firmware size exceeds the flash capacity of the selected chip, please try again after switching to a smaller acoustic model, reducing the number of command words or voice prompts, or using a chip with larger flash capacity.

4. If algorithms are enabled, the system provides relatively less memory space for language model. To ensure normal recognition operation, please reduce the number of command words.

The firmware communication protocol is as follows:
<welcome>:AA 55 01 00 FB:AA 55 01 00 FB
<inactivate>:AA 55 02 00 FB:AA 55 02 00 FB
小幻小幻:AA 55 03 00 FB:AA 55 03 00 FB
增大音量:AA 55 04 00 FB:AA 55 04 00 FB
减小音量:AA 55 05 00 FB:AA 55 05 00 FB
最大音量:AA 55 06 00 FB:AA 55 06 00 FB
中等音量:AA 55 07 00 FB:AA 55 07 00 FB
最小音量:AA 55 08 00 FB:AA 55 08 00 FB
开启播报:AA 55 09 00 FB:AA 55 09 00 FB
关闭播报:AA 55 0A 00 FB:AA 55 0A 00 FB
四:AA 55 00 01 FB:AA 55 00 01 FB
前进:AA 55 00 02 FB:AA 55 00 02 FB
嚄:AA 55 00 03 FB:AA 55 00 03 FB
后退:AA 55 00 04 FB:AA 55 00 04 FB
篇:AA 55 00 05 FB:AA 55 00 05 FB
左转:AA 55 00 06 FB:AA 55 00 06 FB
七七:AA 55 00 07 FB:AA 55 00 07 FB
右转:AA 55 00 08 FB:AA 55 00 08 FB
偶哦:AA 55 00 09 FB:AA 55 00 09 FB
霹雳:AA 55 00 09 FB:AA 55 00 09 FB
坐下:AA 55 00 0A FB:AA 55 00 0A FB
走两步图:AA 55 00 0B FB:AA 55 00 0B FB
站立:AA 55 00 0C FB:AA 55 00 0C FB
应该:AA 55 00 0D FB:AA 55 00 0D FB
停下:AA 55 00 0E FB:AA 55 00 0E FB
唱歌人:AA 55 00 0F FB:AA 55 00 0F FB
降低身体:AA 55 00 10 FB:AA 55 00 10 FB
跳舞:AA 55 00 11 FB:AA 55 00 11 FB
开灯:AA 55 00 12 FB:AA 55 00 12 FB
唱歌:AA 55 00 13 FB:AA 55 00 13 FB
打开门:AA 55 00 14 FB:AA 55 00 14 FB
关闭门:AA 55 00 15 FB:AA 55 00 15 FB
打开水泵:AA 55 00 16 FB:AA 55 00 16 FB
关闭水泵:AA 55 00 17 FB:AA 55 00 17 FB
伸出晾衣架:AA 55 00 18 FB:AA 55 00 18 FB
收回晾衣架:AA 55 00 19 FB:AA 55 00 19 FB
你好:AA 55 00 1A FB:AA 55 00 1A FB
介绍自己:AA 55 00 1B FB:AA 55 00 1B FB
露一手:AA 55 00 1C FB:AA 55 00 1C FB
走两步:AA 55 00 1D FB:AA 55 00 1D FB
摇头:AA 55 00 1E FB:AA 55 00 1E FB
向前扑:AA 55 00 1F FB:AA 55 00 1F FB
向后扑:AA 55 00 20 FB:AA 55 00 20 FB
战斗模式:AA 55 00 21 FB:AA 55 00 21 FB
蹲下来:AA 55 00 22 FB:AA 55 00 22 FB
抖一抖:AA 55 00 23 FB:AA 55 00 23 FB
开风扇:AA 55 00 24 FB:AA 55 00 24 FB
关风扇:AA 55 00 25 FB:AA 55 00 25 FB
转动舵机:AA 55 00 26 FB:AA 55 00 26 FB
亮红灯:AA 55 00 27 FB:AA 55 00 27 FB
亮绿灯:AA 55 00 28 FB:AA 55 00 28 FB
亮蓝灯:AA 55 00 29 FB:AA 55 00 29 FB
显示笑脸:AA 55 00 2A FB:AA 55 00 2A FB
显示哭脸:AA 55 00 2B FB:AA 55 00 2B FB
开启人脸识别:AA 55 00 62 FB:AA 55 00 62 FB
开启标签识别:AA 55 00 63 FB:AA 55 00 63 FB
开启垃圾分类:AA 55 00 64 FB:AA 55 00 64 FB
开启颜色识别:AA 55 00 65 FB:AA 55 00 65 FB
开启巡线功能:AA 55 00 66 FB:AA 55 00 66 FB
开启颜色追踪:AA 55 00 67 FB:AA 55 00 67 FB
开启避障功能:AA 55 00 68 FB:AA 55 00 68 FB
分拣红色:AA 55 00 69 FB:AA 55 00 69 FB
分拣绿色:AA 55 00 6A FB:AA 55 00 6A FB
分拣蓝色:AA 55 00 6B FB:AA 55 00 6B FB
跳舞嗯嗯:AA 55 00 6C FB:AA 55 00 6C FB
俯卧撑:AA 55 00 6D FB:AA 55 00 6D FB
左脚射门:AA 55 00 6E FB:AA 55 00 6E FB
右脚射门:AA 55 00 6F FB:AA 55 00 6F FB
扭腰:AA 55 00 71 FB:AA 55 00 71 FB
仰卧起坐:AA 55 00 72 FB:AA 55 00 72 FB
鞠躬:AA 55 00 73 FB:AA 55 00 73 FB
大鹏展翅:AA 55 00 74 FB:AA 55 00 74 FB
招招手:AA 55 00 75 FB:AA 55 00 75 FB
原地踏步:AA 55 00 76 FB:AA 55 00 76 FB
跌倒起立:AA 55 00 77 FB:AA 55 00 77 FB
大摇大摆:AA 55 00 78 FB:AA 55 00 78 FB
左勾拳:AA 55 00 79 FB:AA 55 00 79 FB
右勾拳:AA 55 00 7A FB:AA 55 00 7A FB
关闭玩法:AA 55 00 7B FB:AA 55 00 7B FB
分拣黄色:AA 55 00 7C FB:AA 55 00 7C FB
执行动作一:AA 55 00 80 FB:AA 55 00 80 FB
执行动作二:AA 55 00 81 FB:AA 55 00 81 FB
执行动作三:AA 55 00 82 FB:AA 55 00 82 FB
执行动作四:AA 55 00 83 FB:AA 55 00 83 FB
执行动作五:AA 55 00 84 FB:AA 55 00 84 FB
执行动作六:AA 55 00 85 FB:AA 55 00 85 FB
执行动作七:AA 55 00 86 FB:AA 55 00 86 FB
执行动作八:AA 55 00 87 FB:AA 55 00 87 FB
执行动作九:AA 55 00 88 FB:AA 55 00 88 FB
执行动作十:AA 55 00 89 FB:AA 55 00 89 FB
执行动作十一:AA 55 00 A1 FB:AA 55 00 A1 FB
执行动作十二:AA 55 00 A2 FB:AA 55 00 A2 FB
执行动作十三:AA 55 00 A3 FB:AA 55 00 A3 FB
执行动作十四:AA 55 00 A4 FB:AA 55 00 A4 FB
执行动作十五:AA 55 00 A5 FB:AA 55 00 A5 FB
执行动作十六:AA 55 00 A6 FB:AA 55 00 A6 FB
执行动作十七:AA 55 00 A7 FB:AA 55 00 A7 FB
执行动作十八:AA 55 00 A8 FB:AA 55 00 A8 FB
执行动作十九:AA 55 00 A9 FB:AA 55 00 A9 FB
执行动作二十:AA 55 00 AA FB:AA 55 00 AA FB
执行动作二十一:AA 55 00 AB FB:AA 55 00 AB FB
执行动作二十二:AA 55 00 AC FB:AA 55 00 AC FB
执行动作二十三:AA 55 00 AD FB:AA 55 00 AD FB
执行动作二十四:AA 55 00 AE FB:AA 55 00 AE FB
执行动作二十五:AA 55 00 AF FB:AA 55 00 AF FB
执行动作二十六:AA 55 00 B0 FB:AA 55 00 B0 FB
执行动作二十七:AA 55 00 B1 FB:AA 55 00 B1 FB
执行动作二十八:AA 55 00 B2 FB:AA 55 00 B2 FB
执行动作二十九:AA 55 00 B3 FB:AA 55 00 B3 FB
执行动作三十:AA 55 00 B4 FB:AA 55 00 B4 FB
可回收物:AA 55 FF 01 FB:AA 55 FF 01 FB
厨余垃圾:AA 55 FF 02 FB:AA 55 FF 02 FB
有害垃圾:AA 55 FF 03 FB:AA 55 FF 03 FB
其他垃圾:AA 55 FF 04 FB:AA 55 FF 04 FB
前方有障碍物:AA 55 FF 05 FB:AA 55 FF 05 FB
完成泊车:AA 55 FF 06 FB:AA 55 FF 06 FB
重新出发:AA 55 FF 07 FB:AA 55 FF 07 FB
识别到左转:AA 55 FF 08 FB:AA 55 FF 08 FB
识别到右转:AA 55 FF 09 FB:AA 55 FF 09 FB
识别到停车:AA 55 FF 0A FB:AA 55 FF 0A FB
识别到红灯:AA 55 FF 0B FB:AA 55 FF 0B FB
识别到绿灯:AA 55 FF 0C FB:AA 55 FF 0C FB
识别到掉头:AA 55 FF 0D FB:AA 55 FF 0D FB
识别到转弯:AA 55 FF 0E FB:AA 55 FF 0E FB
欢迎你:AA 55 FF 0F FB:AA 55 FF 0F FB
发现前方物品，正在抓取:AA 55 FF 10 FB:AA 55 FF 10 FB
发现前方物品，距离过远，无法抓取:AA 55 FF 11 FB:AA 55 FF 11 FB
抓取结束:AA 55 FF 12 FB:AA 55 FF 12 FB
零:AA 55 FF 20 FB:AA 55 FF 20 FB
一:AA 55 FF 21 FB:AA 55 FF 21 FB
二:AA 55 FF 22 FB:AA 55 FF 22 FB
三:AA 55 FF 23 FB:AA 55 FF 23 FB
四:AA 55 FF 24 FB:AA 55 FF 24 FB
五:AA 55 FF 25 FB:AA 55 FF 25 FB
六:AA 55 FF 26 FB:AA 55 FF 26 FB
七:AA 55 FF 27 FB:AA 55 FF 27 FB
八:AA 55 FF 28 FB:AA 55 FF 28 FB
九:AA 55 FF 29 FB:AA 55 FF 29 FB
红色:AA 55 FF 2A FB:AA 55 FF 2A FB
绿色:AA 55 FF 2B FB:AA 55 FF 2B FB
蓝色:AA 55 FF 2C FB:AA 55 FF 2C FB
黄色:AA 55 FF 2D FB:AA 55 FF 2D FB
紫色:AA 55 FF 2E FB:AA 55 FF 2E FB

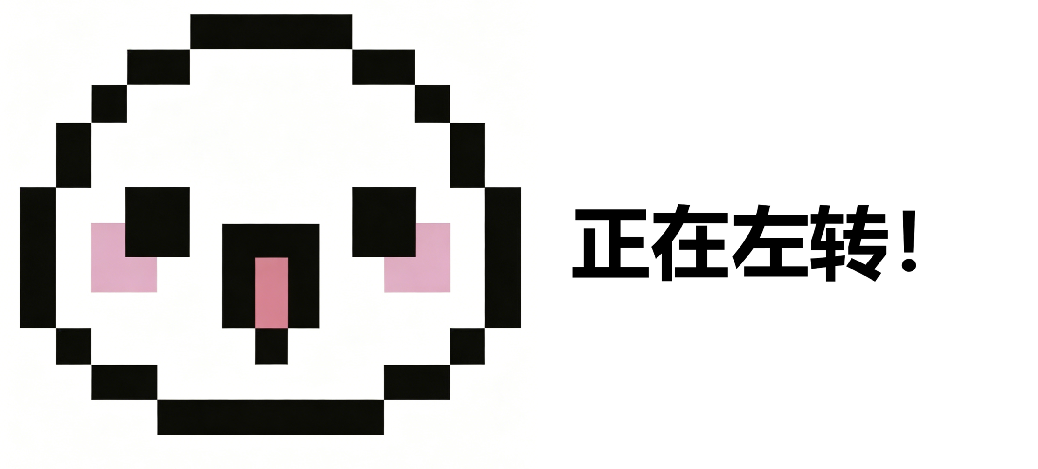
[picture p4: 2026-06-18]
images/原图/70580DD4C71B4541AF086607297D7E0F.png

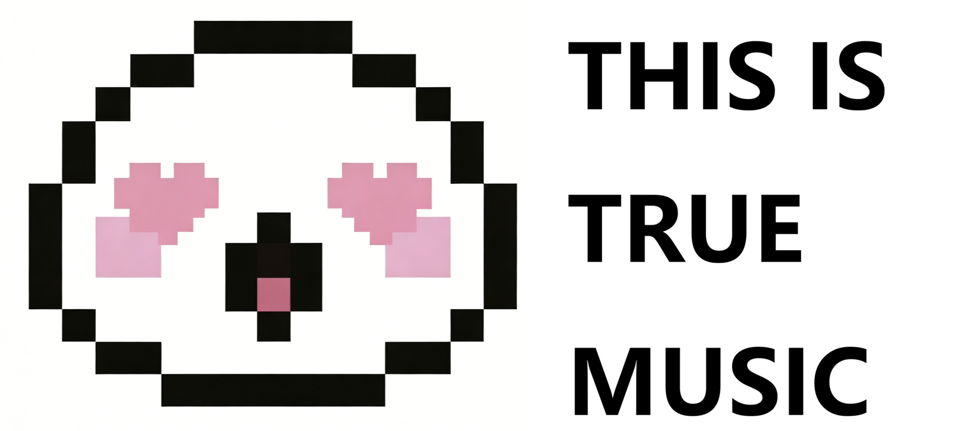
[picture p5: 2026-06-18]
images/原图/放歌.bmp

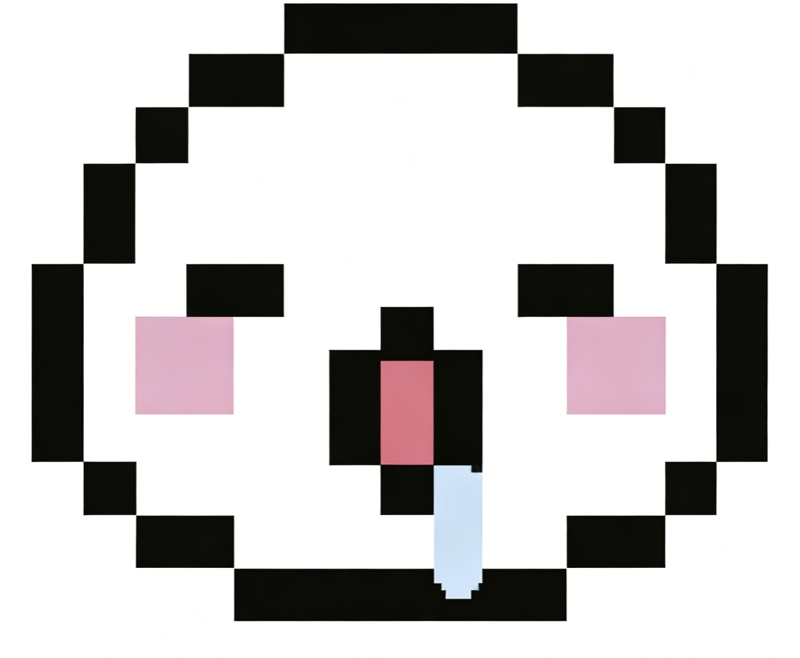
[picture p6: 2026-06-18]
images/原图/9c62d142d18bdfac9d4e2d7346e25402.png

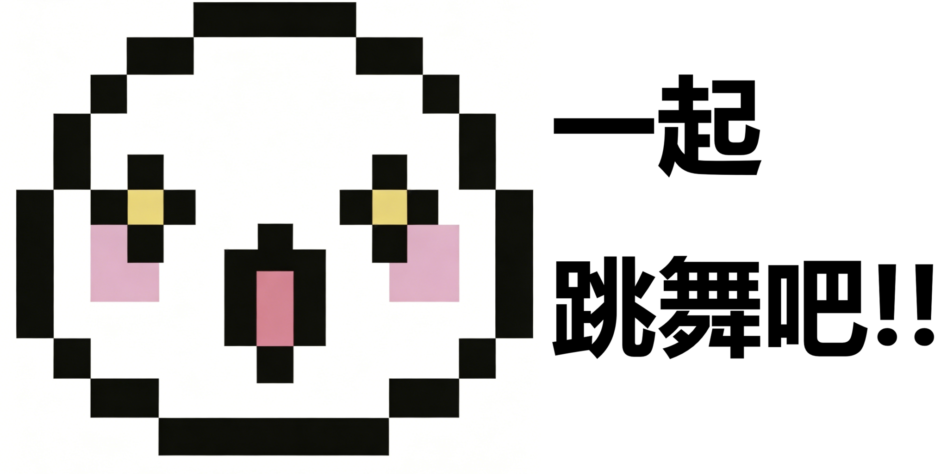
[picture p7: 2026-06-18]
images/原图/跳舞.bmp

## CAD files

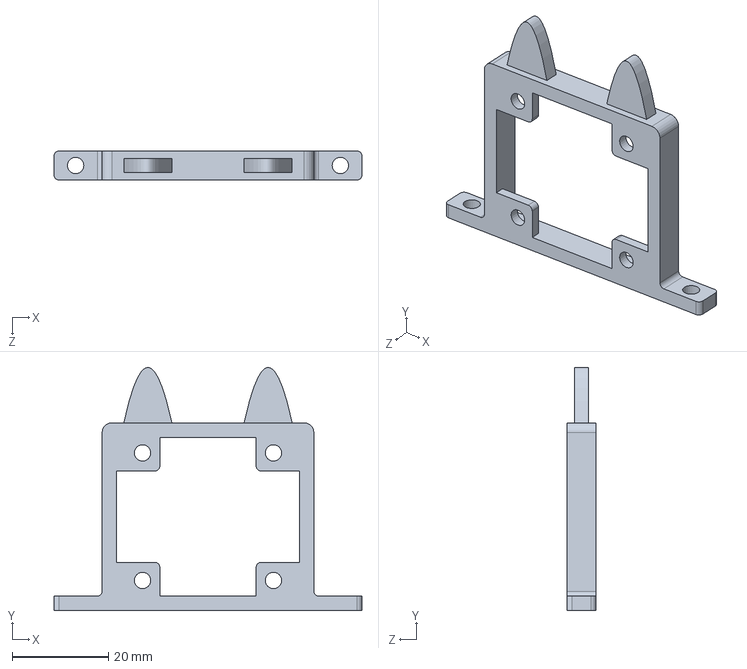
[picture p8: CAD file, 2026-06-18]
model/屏幕固定件2.0.SLDPRT
64.0 x 50.5 x 6.00 mm

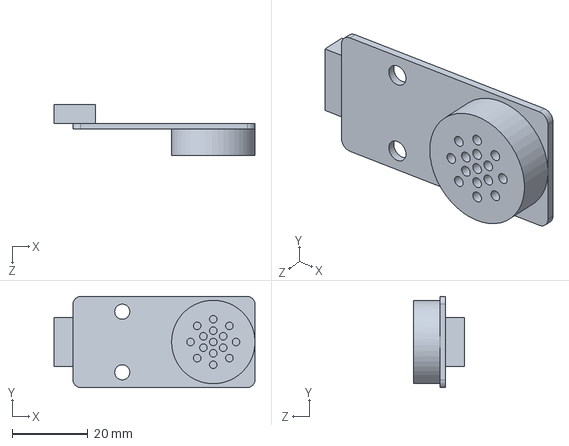
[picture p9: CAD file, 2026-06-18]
model/语音交互模块.SLDPRT
53.0 x 24.0 x 13.5 mm

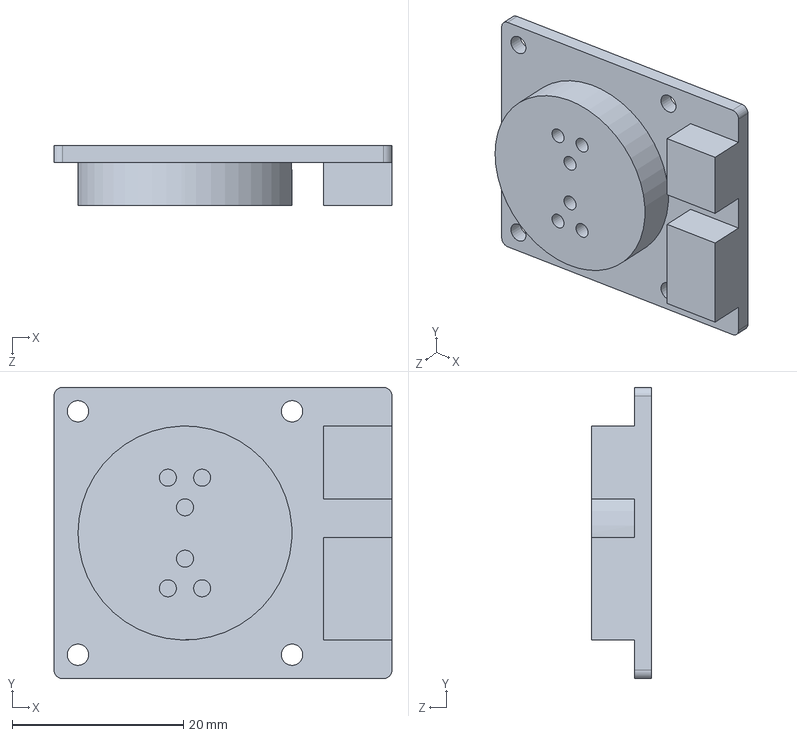
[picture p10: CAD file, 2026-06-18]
model/MP3语音交互模块.SLDPRT
39.5 x 34.0 x 7.00 mm

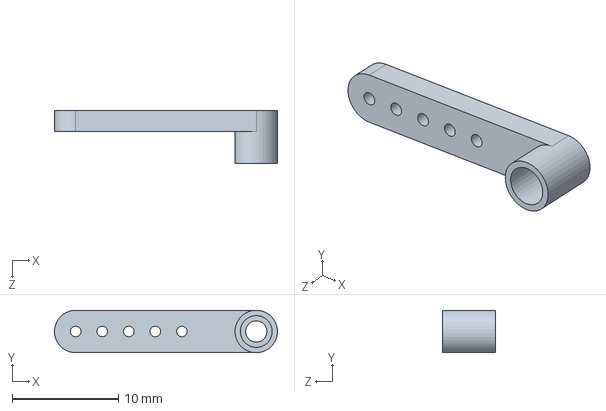
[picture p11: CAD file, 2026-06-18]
model/舵盘.SLDPRT
21.0 x 4.00 x 5.00 mm

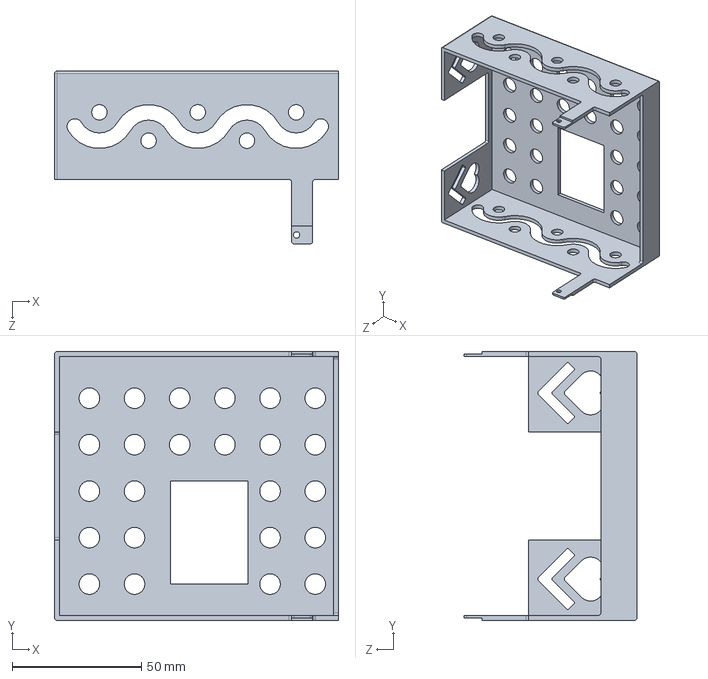
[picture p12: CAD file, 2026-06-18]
model/盖子.SLDPRT
110.0 x 104.2 x 67.0 mm

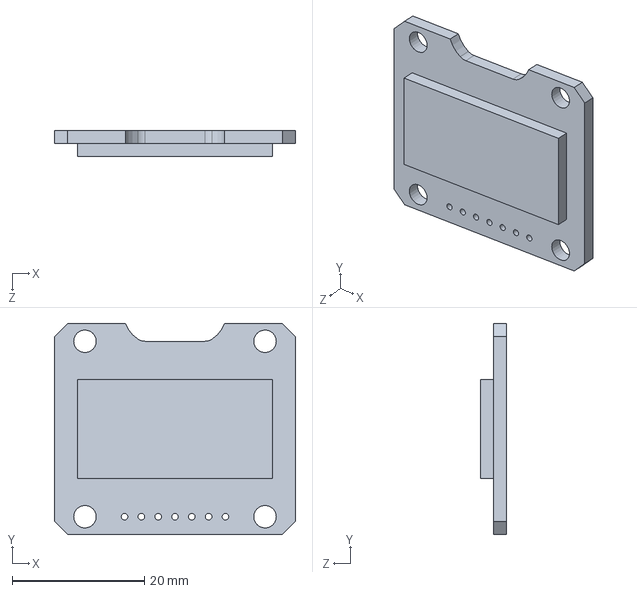
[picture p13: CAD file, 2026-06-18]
model/小屏幕.SLDPRT
36.4 x 31.9 x 4.00 mm

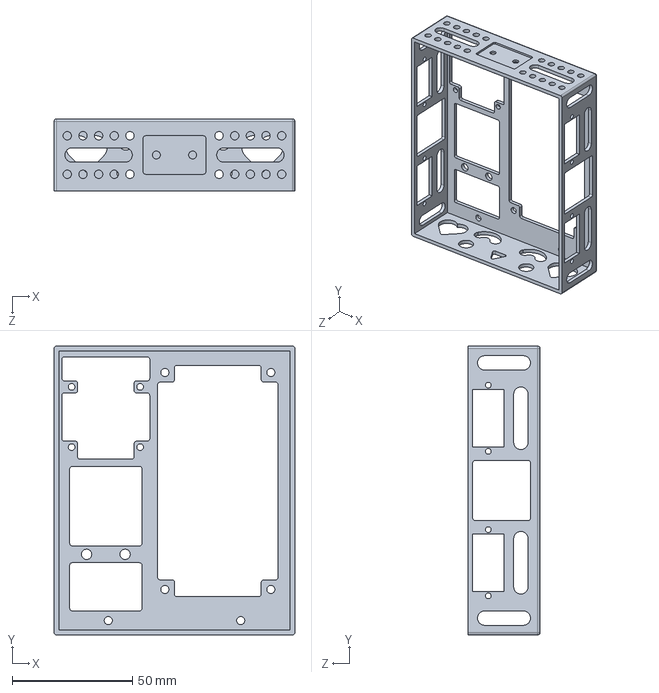
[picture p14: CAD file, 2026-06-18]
model/壳子身体2.0.SLDPRT
100.0 x 120.0 x 30.0 mm

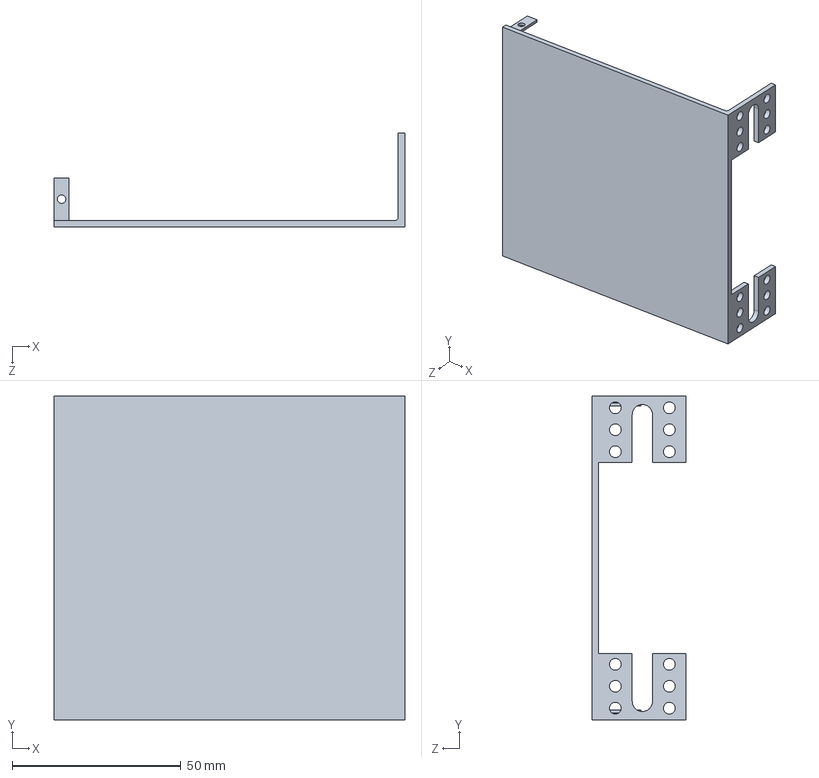
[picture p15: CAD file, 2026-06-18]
model/固定底板.SLDPRT
104.0 x 96.0 x 28.0 mm

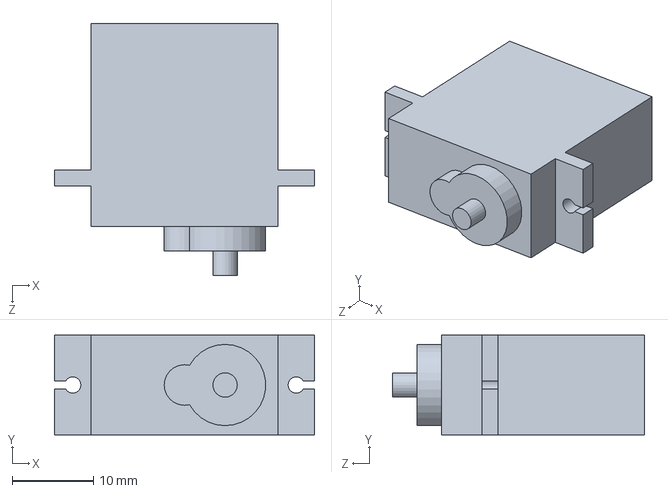
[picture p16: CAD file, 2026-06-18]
model/SG90舵机.SLDPRT
32.0 x 12.3 x 31.0 mm

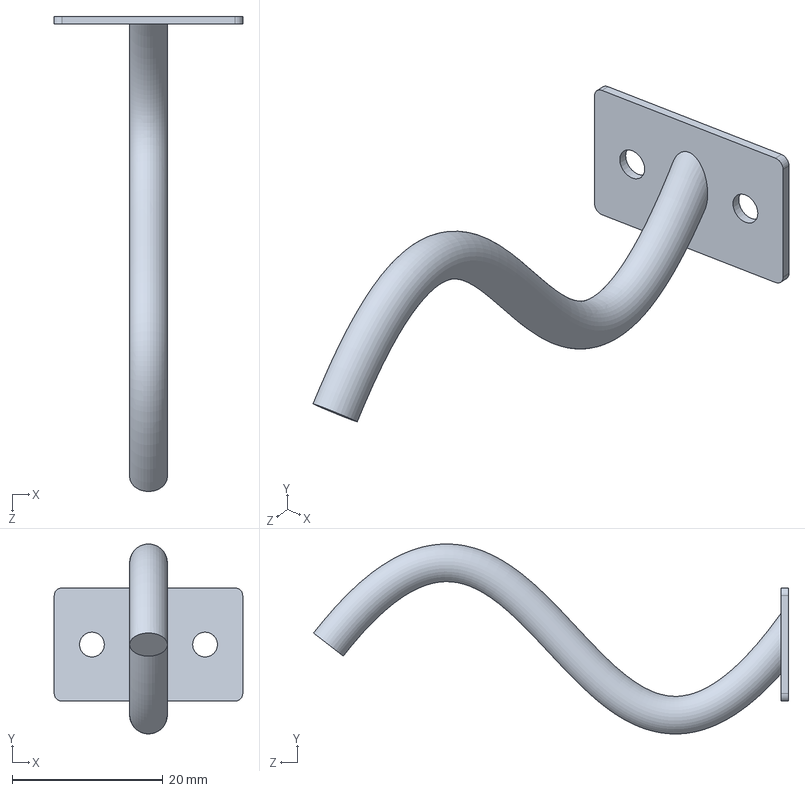
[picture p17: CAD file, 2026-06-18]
model/尾巴.SLDPRT
25.0 x 25.2 x 63.0 mm

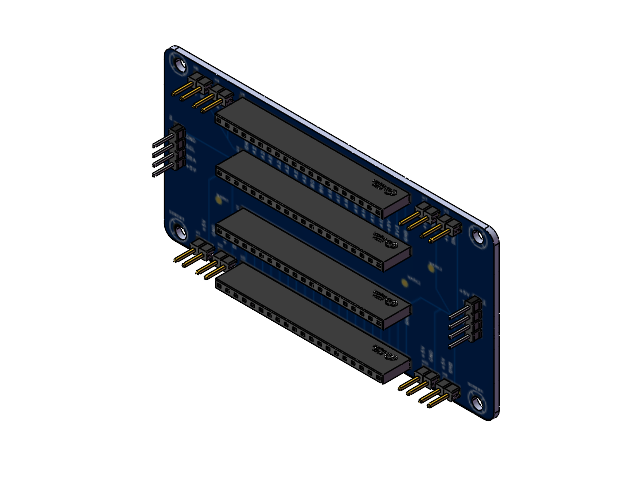
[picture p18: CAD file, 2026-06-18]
model/PCB板.SLDASM
HDR-TH_4P-P2.54-V-M~HDR-TH_4P-P2.54-M-LI-1X4P~dMa8_1 x 2
HDR-TH_20P-P2.54-V-F-2~HDR-TH_20P-P2.54-V-F-2~vcVz_1 x 4
HDR-TH_2P-P2.54-V-M~HDR2.54-M-LI-1X2P~ZAwn_1 x 8
Board~l6kW_1

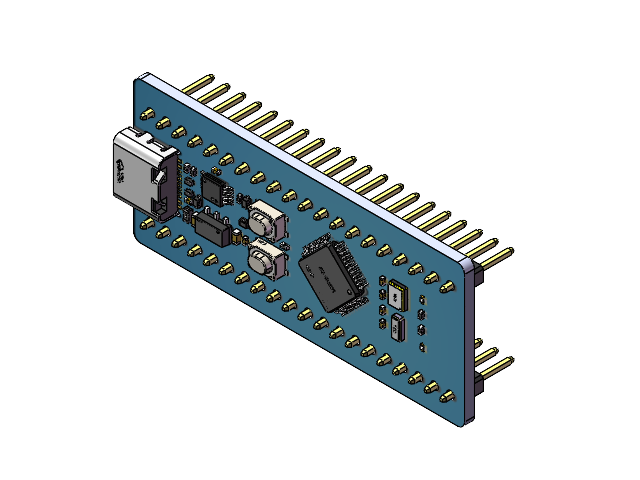
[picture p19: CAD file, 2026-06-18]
model/M0核心板.SLDASM
COMM-TH_L53.3-W22.9-P2.54_LC-DMX-MSPM0G3507~COMM-TH_L53.3-W22.9-P2.54_LC-DMX-MSPM0G3507~nOIs-0_1 x 2
COMM-TH_L53.3-W22.9-P2.54_LC-DMX-MSPM0G3507~COMM-TH_L53.3-W22.9-P2.54_LC-DMX-MSPM0G3507~nOIs-5_1 x 2
COMM-TH_L53.3-W22.9-P2.54_LC-DMX-MSPM0G3507~COMM-TH_L53.3-W22.9-P2.54_LC-DMX-MSPM0G3507~nOIs-8_1 x 13
COMM-TH_L53.3-W22.9-P2.54_LC-DMX-MSPM0G3507~COMM-TH_L53.3-W22.9-P2.54_LC-DMX-MSPM0G3507~nOIs-22_1 x 14
COMM-TH_L53.3-W22.9-P2.54_LC-DMX-MSPM0G3507~COMM-TH_L53.3-W22.9-P2.54_LC-DMX-MSPM0G3507~nOIs-37_1
COMM-TH_L53.3-W22.9-P2.54_LC-DMX-MSPM0G3507~COMM-TH_L53.3-W22.9-P2.54_LC-DMX-MSPM0G3507~nOIs-39_1
COMM-TH_L53.3-W22.9-P2.54_LC-DMX-MSPM0G3507~COMM-TH_L53.3-W22.9-P2.54_LC-DMX-MSPM0G3507~nOIs-41_1
COMM-TH_L53.3-W22.9-P2.54_LC-DMX-MSPM0G3507~COMM-TH_L53.3-W22.9-P2.54_LC-DMX-MSPM0G3507~nOIs-43_1 x 2
COMM-TH_L53.3-W22.9-P2.54_LC-DMX-MSPM0G3507~COMM-TH_L53.3-W22.9-P2.54_LC-DMX-MSPM0G3507~nOIs-46_1
COMM-TH_L53.3-W22.9-P2.54_LC-DMX-MSPM0G3507~COMM-TH_L53.3-W22.9-P2.54_LC-DMX-MSPM0G3507~nOIs-48_1 x 2
COMM-TH_L53.3-W22.9-P2.54_LC-DMX-MSPM0G3507~COMM-TH_L53.3-W22.9-P2.54_LC-DMX-MSPM0G3507~nOIs-51_1
COMM-TH_L53.3-W22.9-P2.54_LC-DMX-MSPM0G3507~COMM-TH_L53.3-W22.9-P2.54_LC-DMX-MSPM0G3507~nOIs-53_1
COMM-TH_L53.3-W22.9-P2.54_LC-DMX-MSPM0G3507~COMM-TH_L53.3-W22.9-P2.54_LC-DMX-MSPM0G3507~nOIs-55_1
COMM-TH_L53.3-W22.9-P2.54_LC-DMX-MSPM0G3507~COMM-TH_L53.3-W22.9-P2.54_LC-DMX-MSPM0G3507~nOIs-57_1 x 2
COMM-TH_L53.3-W22.9-P2.54_LC-DMX-MSPM0G3507~COMM-TH_L53.3-W22.9-P2.54_LC-DMX-MSPM0G3507~nOIs-60_1 x 2
COMM-TH_L53.3-W22.9-P2.54_LC-DMX-MSPM0G3507~COMM-TH_L53.3-W22.9-P2.54_LC-DMX-MSPM0G3507~nOIs-63_1
COMM-TH_L53.3-W22.9-P2.54_LC-DMX-MSPM0G3507~COMM-TH_L53.3-W22.9-P2.54_LC-DMX-MSPM0G3507~nOIs-65_1
COMM-TH_L53.3-W22.9-P2.54_LC-DMX-MSPM0G3507~COMM-TH_L53.3-W22.9-P2.54_LC-DMX-MSPM0G3507~nOIs-67_1 x 2
COMM-TH_L53.3-W22.9-P2.54_LC-DMX-MSPM0G3507~COMM-TH_L53.3-W22.9-P2.54_LC-DMX-MSPM0G3507~nOIs-70_1
COMM-TH_L53.3-W22.9-P2.54_LC-DMX-MSPM0G3507~COMM-TH_L53.3-W22.9-P2.54_LC-DMX-MSPM0G3507~nOIs-71_1

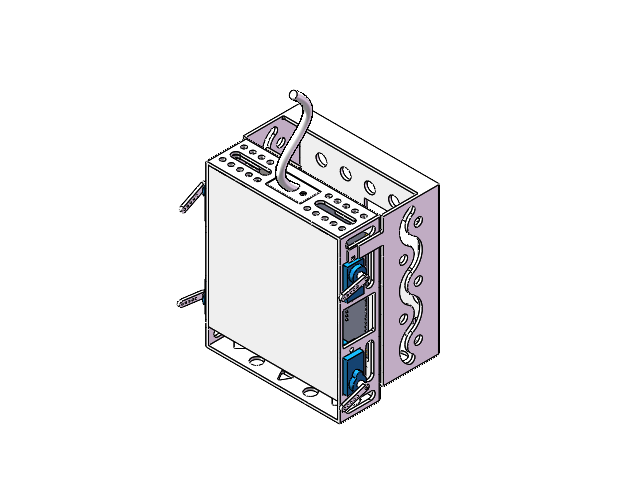
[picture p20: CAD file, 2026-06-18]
model/壳子总装2.0.SLDASM
壳子身体2.0
小屏幕
屏幕固定件2.0
尾巴
SG90舵机 x 4
舵盘 x 4
语音交互模块
COMM-TH_L53.3-W22.9-P2.54_LC-DMX-MSPM0G3507~COMM-TH_L53.3-W22.9-P2.54_LC-DMX-MSPM0G3507~nOIs-0_1 x 2
COMM-TH_L53.3-W22.9-P2.54_LC-DMX-MSPM0G3507~COMM-TH_L53.3-W22.9-P2.54_LC-DMX-MSPM0G3507~nOIs-5_1 x 2
COMM-TH_L53.3-W22.9-P2.54_LC-DMX-MSPM0G3507~COMM-TH_L53.3-W22.9-P2.54_LC-DMX-MSPM0G3507~nOIs-8_1 x 13
COMM-TH_L53.3-W22.9-P2.54_LC-DMX-MSPM0G3507~COMM-TH_L53.3-W22.9-P2.54_LC-DMX-MSPM0G3507~nOIs-22_1 x 14
COMM-TH_L53.3-W22.9-P2.54_LC-DMX-MSPM0G3507~COMM-TH_L53.3-W22.9-P2.54_LC-DMX-MSPM0G3507~nOIs-37_1
COMM-TH_L53.3-W22.9-P2.54_LC-DMX-MSPM0G3507~COMM-TH_L53.3-W22.9-P2.54_LC-DMX-MSPM0G3507~nOIs-39_1
COMM-TH_L53.3-W22.9-P2.54_LC-DMX-MSPM0G3507~COMM-TH_L53.3-W22.9-P2.54_LC-DMX-MSPM0G3507~nOIs-41_1
COMM-TH_L53.3-W22.9-P2.54_LC-DMX-MSPM0G3507~COMM-TH_L53.3-W22.9-P2.54_LC-DMX-MSPM0G3507~nOIs-43_1 x 2
COMM-TH_L53.3-W22.9-P2.54_LC-DMX-MSPM0G3507~COMM-TH_L53.3-W22.9-P2.54_LC-DMX-MSPM0G3507~nOIs-46_1
COMM-TH_L53.3-W22.9-P2.54_LC-DMX-MSPM0G3507~COMM-TH_L53.3-W22.9-P2.54_LC-DMX-MSPM0G3507~nOIs-48_1 x 2
COMM-TH_L53.3-W22.9-P2.54_LC-DMX-MSPM0G3507~COMM-TH_L53.3-W22.9-P2.54_LC-DMX-MSPM0G3507~nOIs-51_1
COMM-TH_L53.3-W22.9-P2.54_LC-DMX-MSPM0G3507~COMM-TH_L53.3-W22.9-P2.54_LC-DMX-MSPM0G3507~nOIs-53_1
COMM-TH_L53.3-W22.9-P2.54_LC-DMX-MSPM0G3507~COMM-TH_L53.3-W22.9-P2.54_LC-DMX-MSPM0G3507~nOIs-55_1
COMM-TH_L53.3-W22.9-P2.54_LC-DMX-MSPM0G3507~COMM-TH_L53.3-W22.9-P2.54_LC-DMX-MSPM0G3507~nOIs-57_1 x 2
COMM-TH_L53.3-W22.9-P2.54_LC-DMX-MSPM0G3507~COMM-TH_L53.3-W22.9-P2.54_LC-DMX-MSPM0G3507~nOIs-60_1 x 2
COMM-TH_L53.3-W22.9-P2.54_LC-DMX-MSPM0G3507~COMM-TH_L53.3-W22.9-P2.54_LC-DMX-MSPM0G3507~nOIs-63_1
COMM-TH_L53.3-W22.9-P2.54_LC-DMX-MSPM0G3507~COMM-TH_L53.3-W22.9-P2.54_LC-DMX-MSPM0G3507~nOIs-65_1
COMM-TH_L53.3-W22.9-P2.54_LC-DMX-MSPM0G3507~COMM-TH_L53.3-W22.9-P2.54_LC-DMX-MSPM0G3507~nOIs-67_1 x 2
COMM-TH_L53.3-W22.9-P2.54_LC-DMX-MSPM0G3507~COMM-TH_L53.3-W22.9-P2.54_LC-DMX-MSPM0G3507~nOIs-70_1
COMM-TH_L53.3-W22.9-P2.54_LC-DMX-MSPM0G3507~COMM-TH_L53.3-W22.9-P2.54_LC-DMX-MSPM0G3507~nOIs-71_1
HDR-TH_4P-P2.54-V-M~HDR-TH_4P-P2.54-M-LI-1X4P~dMa8_1 x 2
HDR-TH_20P-P2.54-V-F-2~HDR-TH_20P-P2.54-V-F-2~vcVz_1 x 4
HDR-TH_2P-P2.54-V-M~HDR2.54-M-LI-1X2P~ZAwn_1 x 8
Board~l6kW_1
MP3语音交互模块
盖子
固定底板

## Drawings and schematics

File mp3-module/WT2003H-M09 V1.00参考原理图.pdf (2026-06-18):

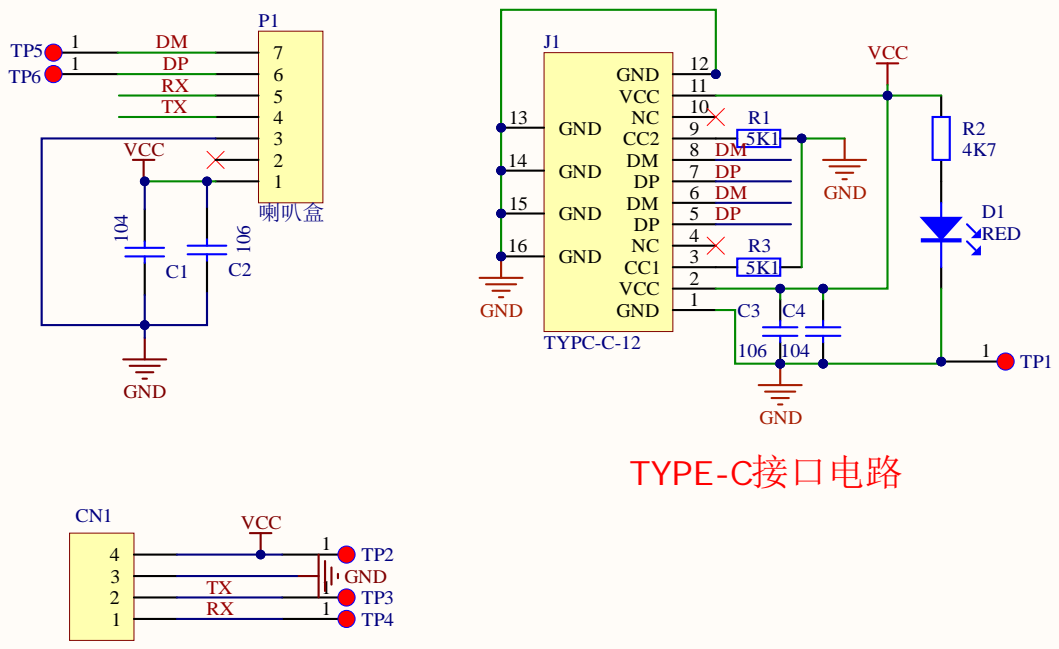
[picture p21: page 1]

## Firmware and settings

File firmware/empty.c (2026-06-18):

/*===========================================================================
 * M03507 (地猛星 MSPM0G3507) + CI1302 语音 + OLED 屏 + 舵机
 *
 * 屏幕: 1.3寸 SH1106 OLED (128x64 单色 SPI)
 *
 * 硬件引脚:
 *   PA14 = LED (板载)
 *   PA10 = UART0 TX (调试/printf)
 *   PA11 = UART0 RX
 *   PB2  = I2C SCL → CI1302 SCL
 *   PB3  = I2C SDA → CI1302 SDA
 *
 *   OLED SPI (软件模拟, 引脚避开舵机PA15/PA21):
 *     PA12 = SCL, PA13 = SDA, PA17 = RES, PA16 = DC, PA22 = CS
 *
 *   舵机 (4路独立PWM):
 *     PA15 = TIMA1 CCP0 = PWM_1 = 前左腿 (FL)
 *     PA0  = TIMA0 CCP0 = PWM_2 = 前右腿 (FR)
 *     PA21 = TIMG6 CCP0 = PWM_3 = 后左腿 (RL)
 *     PA23 = TIMG0 CCP0 = PWM_4 = 后右腿 (RR)
 *=========================================================================*/

#include "ti_msp_dl_config.h"
#include <stdint.h>
#include <stdio.h>
#include "board.h"
#include "LCD/lcd_init.h"
#include "LCD/lcd.h"

/* ---- 图片头文件 (用 Image2Lcd 取模后替换数组) ---- */
#include "LCD/img_idle.h"
#include "LCD/img_go.h"
#include "LCD/img_back.h"
#include "LCD/img_left.h"
#include "LCD/img_right.h"
#include "LCD/img_sit.h"
#include "LCD/img_walk.h"
#include "LCD/img_stop.h"
#include "LCD/img_dance.h"
#include "LCD/img_sing.h"
#include "LCD/img_sleep.h"



/*===========================================================================
 * 1. CI1302 语音模块 — 软件 I2C (PB2/PB3)
 *=========================================================================*/
#ifndef CI1302_SCL_IOMUX
#define CI1302_SCL_IOMUX  I2C_CI1302_SCL_IOMUX
#endif
#ifndef CI1302_SDA_IOMUX
#define CI1302_SDA_IOMUX  I2C_CI1302_SDA_IOMUX
#endif

#define CI1302_PORT       GPIOB
#define CI1302_SCL_PIN    DL_GPIO_PIN_2
#define CI1302_SDA_PIN    DL_GPIO_PIN_3
#define CI1302_ADDR       0x34
#define CI1302_RESULT_REG 0x64
#define CI1302_SPEAK_REG  0x6E
#define CI1302_CMD        0x00
#define CI1302_ANNOUNCE   0xFF

#define CI1302_SDA_OUT() {                                        \
    DL_GPIO_initDigitalOutput(CI1302_SDA_IOMUX);                  \
    DL_GPIO_setPins(CI1302_PORT, CI1302_SDA_PIN);                 \
    DL_GPIO_enableOutput(CI1302_PORT, CI1302_SDA_PIN);            \
}
#define CI1302_SDA_IN()  { DL_GPIO_initDigitalInput(CI1302_SDA_IOMUX); }
#define CI1302_SDA_GET() ( (DL_GPIO_readPins(CI1302_PORT,CI1302_SDA_PIN) \
                          & CI1302_SDA_PIN) ? 1 : 0 )
#define CI1302_SDA(x)   ((x) ? DL_GPIO_setPins(CI1302_PORT,CI1302_SDA_PIN)   \
                             : DL_GPIO_clearPins(CI1302_PORT,CI1302_SDA_PIN))
#define CI1302_SCL(x)   ((x) ? DL_GPIO_setPins(CI1302_PORT,CI1302_SCL_PIN)   \
                             : DL_GPIO_clearPins(CI1302_PORT,CI1302_SCL_PIN))

static void I2C_Start(void)
{
    CI1302_SDA_OUT();
    CI1302_SCL(0); CI1302_SDA(1); CI1302_SCL(1);
    delay_us(5);   CI1302_SDA(0);
    delay_us(5);   CI1302_SCL(0);
    delay_us(5);
}

static void I2C_Stop(void)
{
    CI1302_SDA_OUT();
    CI1302_SCL(0); CI1302_SDA(0); CI1302_SCL(1);
    delay_us(5);   CI1302_SDA(1);
    delay_us(5);
}

static uint8_t I2C_Wait_Ack(void)
{
    unsigned char ack_flag = 10;
    CI1302_SDA_IN(); CI1302_SDA(1); delay_us(5);
    CI1302_SCL(1);   delay_us(5);
    while ((CI1302_SDA_GET() == 1) && ack_flag) {
        ack_flag--; delay_us(5);
    }
    if (ack_flag <= 0) { I2C_Stop(); return 1; }
    CI1302_SCL(0); CI1302_SDA_OUT();
    return 0;
}

static void I2C_Send_Ack(uint8_t ack)
{
    CI1302_SDA_OUT(); CI1302_SCL(0); CI1302_SDA(0); delay_us(5);
    if (!ack) CI1302_SDA(0); else CI1302_SDA(1);
    CI1302_SCL(1); delay_us(5);
    CI1302_SCL(0); CI1302_SDA(1);
}

static void I2C_Write(uint8_t data)
{
    int i;
    CI1302_SDA_OUT(); CI1302_SCL(0);
    for (i = 0; i < 8; i++) {
        CI1302_SDA((data & 0x80) >> 7);
        delay_us(2); data <<= 1; delay_us(6);
        CI1302_SCL(1); delay_us(4);
        CI1302_SCL(0); delay_us(4);
    }
}

static uint8_t I2C_Read(void)
{
    unsigned char i, receive = 0;
    CI1302_SDA_IN();
    for (i = 0; i < 8; i++) {
        CI1302_SCL(0); delay_us(5);
        CI1302_SCL(1); delay_us(5);
        receive <<= 1;
        if (CI1302_SDA_GET()) receive |= 1;
        delay_us(5);
    }
    return receive;
}

uint8_t CI1302_Recognition(void)
{
    uint8_t result = 0;
    I2C_Start();
    I2C_Write(CI1302_ADDR << 1 | 0);
    if (I2C_Wait_Ack() == 1) goto err;
    I2C_Write(CI1302_RESULT_REG);
    if (I2C_Wait_Ack() == 1) goto err;
    I2C_Stop();

    I2C_Start();
    I2C_Write(CI1302_ADDR << 1 | 1);
    if (I2C_Wait_Ack() == 1) goto err;
    result = I2C_Read();
    I2C_Send_Ack(1);
    I2C_Stop();
    return result;

err:
    I2C_Stop();
    return 0;
}

void CI1302_Speak(uint8_t type, uint8_t id)
{
    if (type != CI1302_CMD && type != CI1302_ANNOUNCE) return;
    I2C_Start();
    I2C_Write(CI1302_ADDR << 1 | 0);
    if (I2C_Wait_Ack() == 1) goto err;
    I2C_Write(CI1302_SPEAK_REG);
    if (I2C_Wait_Ack() == 1) goto err;
    I2C_Write(type);
    if (I2C_Wait_Ack() == 1) goto err;
    I2C_Write(id);
    if (I2C_Wait_Ack() == 1) goto err;
    I2C_Stop();
    delay_ms(30);
    return;
err:
    I2C_Stop();
}

/*===========================================================================
 * 2. OLED 显示 — 取代 TJC 串口屏
 *=========================================================================*/

/* ---- 命令名称映射 ---- */
static const char* GetCmdName(uint8_t id)
{
    switch (id) {
    case 0x01: return "Forward";
    case 0x02: return "Backward";
    case 0x03: return "Left";
    case 0x04: return "Right";
    case 0x05: return "Sit";
    case 0x06: return "tand";
    case 0x07: return "Stop";
    case 0x08: return "Dance";
    case 0x09: return "Sing";
    default:   return "Idle";
    }
}

/* Image2Lcd 头: [scan][bpp][w_lo][w_hi][h_lo][h_hi], 6字节 */
#define IMG_W(p)  ((u16)((p)[2] | ((u16)((p)[3] << 8))))
#define IMG_H(p)  ((u16)((p)[4] | ((u16)((p)[5] << 8))))

/* 命令ID → 图片数组映射 */
static const u8* GetCmdImage(uint8_t cmdId, u8 *w, u8 *h)
{
    const u8 *pic = NULL;
    switch (cmdId) {
    case 0x01: pic = gImage_go;    break;
    case 0x02: pic = gImage_back;  break;
    case 0x03: pic = gImage_left;  break;  // 左转
    case 0x04: pic = gImage_right; break;  // 右转
    case 0x05: pic = gImage_sit;   break;
    case 0x06: pic = gImage_walk;  break;
    case 0x07: pic = gImage_sleep;  break;
    case 0x08: pic = gImage_dance;  break;  // 跳舞
    case 0x09: pic = gImage_sing; break;  // 唱歌
    default:   pic = gImage_idle;  break;
    }
    /* 从Image2Lcd头自动读取宽高 (头6字节有效则w>0) */
    *w = IMG_W(pic);
    *h = IMG_H(pic);
    return (*w > 0 && *w <= 128) ? pic : NULL;
}

/* OLED 显示更新 (自动匹配图片) */
static void OLED_DisplayCommand(uint8_t cmdId)
{
    u8 w, h;
    const u8 *pic = GetCmdImage(cmdId, &w, &h);

    OLED_Clear(0);

    if (pic) {
        /* 有图片: 图片居中显示 */
        OLED_ShowBMP((128 - w) / 2, 0, w, h, pic + 6, 1);
        /* 底部显示命令名 */
        LCD_ShowString(0, 52, (u8 *)GetCmdName(cmdId), RED, BLACK, 12, 0);
    } else {
        /* 无图片: 大字显示命令名 */
        LCD_ShowString(0, 8,  (u8 *)GetCmdName(cmdId), RED, BLACK, 16, 0);
        LCD_ShowString(0, 36, (u8 *)"CMD: 0x", RED, BLACK, 12, 0);
        {
            char hex[3];
            hex[0] = "0123456789ABCDEF"[cmdId >> 4];
            hex[1] = "0123456789ABCDEF"[cmdId & 0x0F];
            hex[2] = '\0';
            LCD_ShowString(48, 36, (u8 *)hex, RED, BLACK, 12, 0);
        }
    }

    OLED_Refresh();
}

/* 简化版: 纯文字显示 */
static void OLED_ShowText(const char *line1, const char *line2)
{
    OLED_Clear(0);
    if (line1) LCD_ShowString(0, 8,  (u8 *)line1, RED, BLACK, 16, 0);
    if (line2) LCD_ShowString(0, 32, (u8 *)line2, RED, BLACK, 12, 0);
    OLED_Refresh();
}

/*===========================================================================
 * 3. WT2003H4 MP3 模块 — UART1 (PA8/PA9, 115200)
 *
 *   RX ← PA8 (MCU TX), TX → PA9 (MCU RX, 可选)
 *   协议: 7E + 长度 + 命令 + 参数 + 校验和 + EF
 *=========================================================================*/

/* 发送一帧 */
static void MP3_SendCmd(uint8_t cmd, uint8_t *param, uint8_t paramLen)
{
    uint8_t len = 2 + paramLen;
    uint8_t checksum = len + cmd;
    uint8_t i;
    for (i = 0; i < paramLen; i++) checksum += param[i];

    DL_UART_Main_transmitDataBlocking(UART_1_INST, 0x7E);
    DL_UART_Main_transmitDataBlocking(UART_1_INST, len);
    DL_UART_Main_transmitDataBlocking(UART_1_INST, cmd);
    for (i = 0; i < paramLen; i++)
        DL_UART_Main_transmitDataBlocking(UART_1_INST, param[i]);
    DL_UART_Main_transmitDataBlocking(UART_1_INST, checksum);
    DL_UART_Main_transmitDataBlocking(UART_1_INST, 0xEF);
}

/* 播放第 N 首 (索引) */
#define MP3_Play(n) do { uint8_t _p[]={0x00,(n)}; MP3_SendCmd(0xA0,_p,2); } while(0)

/* 停止 */
#define MP3_Stop()      MP3_SendCmd(0xAB, NULL, 0)

/* 音量 0~31 */
void MP3_SetVolume(uint8_t vol)
{
    if (vol > 31) vol = 31;
    uint8_t ck = 0x04 + 0xAE + vol;
    const uint8_t cmd[] = {0x7E, 0x04, 0xAE, vol, ck, 0xEF};
    MP3_SendCmd(0xAE, &vol, 1);
}

/*===========================================================================
 * 4. 舵机 PWM — 4路独立PWM实例
 *=========================================================================*/
#define SERVO_CH_FL     0
#define SERVO_CH_FR     1
#define SERVO_CH_RL     2
#define SERVO_CH_RR     3

#define SERVO_MIN_CCR    0
#define SERVO_MAX_CCR    2500
#define SERVO_MID_CCR    750

static uint16_t g_servoCCR[4] = {SERVO_MID_CCR, SERVO_MID_CCR,
                                  SERVO_MID_CCR, SERVO_MID_CCR};

/* 单腿方向: 1=反相(1500-x), 0=正常  [FL, FR, RL, RR] */
static const int8_t g_legInv[4] = {0, 1, 0, 1};

static void Servo_WriteCCR(uint8_t ch, uint16_t ccr)
{
    switch (ch) {
    case 0: DL_TimerA_setCaptureCompareValue(PWM_1_INST, ccr, GPIO_PWM_1_C0_IDX); break;
    case 1: DL_TimerA_setCaptureCompareValue(PWM_2_INST, ccr, GPIO_PWM_2_C0_IDX); break;
    case 2: DL_TimerG_setCaptureCompareValue(PWM_3_INST, ccr, GPIO_PWM_3_C0_IDX); break;
    case 3: DL_TimerG_setCaptureCompareValue(PWM_4_INST, ccr, GPIO_PWM_4_C0_IDX); break;
    }
}

void Servo_SetCCR(uint8_t ch, uint16_t ccr)
{
    if (ccr < SERVO_MIN_CCR) ccr = SERVO_MIN_CCR;
    if (ccr > SERVO_MAX_CCR) ccr = SERVO_MAX_CCR;
    g_servoCCR[ch] = ccr;
    Servo_WriteCCR(ch, ccr);
}

void Servo_AllMid(void)
{
    Servo_SetCCR(0, SERVO_MID_CCR); Servo_SetCCR(1, SERVO_MID_CCR);
    Servo_SetCCR(2, SERVO_MID_CCR); Servo_SetCCR(3, SERVO_MID_CCR);
}

void Servo_Init(void)
{
    Servo_AllMid();
    printf("[SERVO] 4ch ready\r\n");
}

/* 双舵机同步移动 (阻塞, 用于左转/右转等一次性动作) */
void Servo_Move2CCR(uint8_t c0, uint16_t t0, uint8_t c1, uint16_t t1,
                    uint8_t stepMs, uint8_t stepCCR)
{
    int32_t p0 = g_servoCCR[c0], p1 = g_servoCCR[c1];
    uint8_t d0 = (p0 == t0), d1 = (p1 == t1);
    if (d0 && d1) return;
    while (!d0 || !d1) {
        if (!d0) { Servo_WriteCCR(c0, (uint16_t)p0);
            if (t0 > p0) { p0 += (1+stepCCR); if (p0 >= t0) {p0=t0; d0=1;} }
            else         { p0 -= (1+stepCCR); if (p0 <= t0) {p0=t0; d0=1;} }
        }
        if (!d1) { Servo_WriteCCR(c1, (uint16_t)p1);
            if (t1 > p1) { p1 += (1+stepCCR); if (p1 >= t1) {p1=t1; d1=1;} }
            else         { p1 -= (1+stepCCR); if (p1 <= t1) {p1=t1; d1=1;} }
        }
        if (!d0 || !d1) delay_ms(stepMs);
    }
    Servo_WriteCCR(c0, t0); Servo_WriteCCR(c1, t1);
    g_servoCCR[c0] = t0; g_servoCCR[c1] = t1;
}

/*===========================================================================
 * 数控振荡器 (NCO) 步态引擎 — 非阻塞, 平滑正弦轨迹
 *
 *  前进: MID → MID-1125 → MID+1125 → MID (750→1875→3000→1875)
 *  后退: MID → MID+1125 → MID-1125 → MID
 *
 *  参数说明:
 *    CYCLE_STEPS    = 周期步数 (越大越慢越平滑)
 *    CYCLE_DELAY_MS = 每步延时 (配合 STEP 控制周期时间)
 *    SMOOTH_STEP    = 每步 CCR 逼近量 (越大响应越快)
 *    LAG_STEPS      = 对侧腿滞后步数 (行走时转弯用)
 *=========================================================================*/
#define CYCLE_STEPS     100
#define CYCLE_DELAY_MS  5
#define SMOOTH_STEP     30
#define LAG_STEPS       (CYCLE_STEPS / 2)
#define PHASE_LEN       (CYCLE_STEPS / 3)

/* 前进: 快前摆10% → 慢后推90% */

static uint16_t Gait_ForwardCCR(uint16_t t)
{
    t %= CYCLE_STEPS;
		
    if(t < 10)
{
    return 1050 - t * 60;
}
else
{
    return 450 + (t - 10) * 6;
}
}
/* 后退: 快后摆10% → 慢前推80% */
static uint16_t Gait_BackwardCCR(uint16_t t)
{
    t %= 100;

    if(t < 10)
    {
        return 450 + t * 60;
    }
    else
    {
        return 1050 - (t - 10) * 6;
    }
}

typedef enum {
    GAIT_IDLE = 0,
    GAIT_FORWARD,
    GAIT_BACKWARD,
    GAIT_TURN_LEFT,
    GAIT_TURN_RIGHT,
    GAIT_DANCE,
} GaitState;

/*
 * 非阻塞步态更新 — 每次主循环调用一次
 *   计算目标 CCR → 平滑逼近 → 写入 PWM
 */
void Servo_GaitUpdate(GaitState gs, uint16_t step)
{
    uint16_t tL, tR, target[4];

    switch (gs) {
    case GAIT_FORWARD:
        tL = step;
        tR = (step + CYCLE_STEPS - LAG_STEPS) % CYCLE_STEPS;
        { uint16_t v0 = Gait_ForwardCCR(tL); target[0]=g_legInv[0]?(1500-v0):v0; }
        { uint16_t v1 = Gait_ForwardCCR(tR); target[1]=g_legInv[1]?(1500-v1):v1; }
        { uint16_t v2 = Gait_ForwardCCR(tR); target[2]=g_legInv[2]?(1500-v2):v2; }
        { uint16_t v3 = Gait_ForwardCCR(tL); target[3]=g_legInv[3]?(1500-v3):v3; }
        break;

    case GAIT_BACKWARD:
        tL = step;
        tR = (step + CYCLE_STEPS - LAG_STEPS) % CYCLE_STEPS;
        { uint16_t v0 = Gait_BackwardCCR(tL); target[0]=g_legInv[0]?(1500-v0):v0; }
        { uint16_t v1 = Gait_BackwardCCR(tR); target[1]=g_legInv[1]?(1500-v1):v1; }
        { uint16_t v2 = Gait_BackwardCCR(tR); target[2]=g_legInv[2]?(1500-v2):v2; }
        { uint16_t v3 = Gait_BackwardCCR(tL); target[3]=g_legInv[3]?(1500-v3):v3; }
        break;

    case GAIT_TURN_LEFT:
        /* 左转: 右半身前推+左半身后推 → 原地左旋 */
        /* 配对: FL+RR(左) vs FR+RL(右), 对角交替 */
        tL = step;
        tR = (step + CYCLE_STEPS - LAG_STEPS) % CYCLE_STEPS;
        { uint16_t v0 = Gait_BackwardCCR(tL); target[0]=g_legInv[0]?(1500-v0):v0; }
        { uint16_t v1 = Gait_ForwardCCR(tR);  target[1]=g_legInv[1]?(1500-v1):v1; }
        { uint16_t v2 = Gait_BackwardCCR(tR); target[2]=g_legInv[2]?(1500-v2):v2; }
        { uint16_t v3 = Gait_ForwardCCR(tL);  target[3]=g_legInv[3]?(1500-v3):v3; }
        break;

    case GAIT_TURN_RIGHT:
        /* 右转: 左半身前推+右半身后推 → 原地右旋 */
        tL = step;
        tR = (step + CYCLE_STEPS - LAG_STEPS) % CYCLE_STEPS;
        { uint16_t v0 = Gait_ForwardCCR(tL);  target[0]=g_legInv[0]?(1500-v0):v0; }
        { uint16_t v1 = Gait_BackwardCCR(tR); target[1]=g_legInv[1]?(1500-v1):v1; }
        { uint16_t v2 = Gait_ForwardCCR(tR);  target[2]=g_legInv[2]?(1500-v2):v2; }
        { uint16_t v3 = Gait_BackwardCCR(tL); target[3]=g_legInv[3]?(1500-v3):v3; }
        break;

    case GAIT_DANCE:
        /* 4相波浪: FL→FR→RL→RR 依次起伏, 每腿差1/4周期 */
        /* 前腿+后腿反相: 形成身体前后摇摆的跳舞效果 */
        { uint16_t v0 = Gait_ForwardCCR(step);                        target[0]=g_legInv[0]?(1500-v0):v0; }
        { uint16_t v1 = Gait_ForwardCCR(step + CYCLE_STEPS/4);        target[1]=g_legInv[1]?(1500-v1):v1; }
        { uint16_t v2 = Gait_BackwardCCR(step + CYCLE_STEPS*2/4);     target[2]=g_legInv[2]?(1500-v2):v2; }
        { uint16_t v3 = Gait_BackwardCCR(step + CYCLE_STEPS*3/4);     target[3]=g_legInv[3]?(1500-v3):v3; }
        break;

    default:
        return;
    }

    /* 平滑逼近 */
    for (int ch = 0; ch < 4; ch++) {
        uint16_t cur = g_servoCCR[ch];
        if (cur < target[ch])      { cur += SMOOTH_STEP; if (cur > target[ch]) cur = target[ch]; }
        else if (cur > target[ch]) { cur -= SMOOTH_STEP; if (cur < target[ch]) cur = target[ch]; }
        g_servoCCR[ch] = cur;
        Servo_WriteCCR(ch, cur);
    }
}

/* 坐下 (阻塞, 一次性动作)
 *   前腿 → 中立位 750
 *   后腿 → 相对中立位前弯 90° (RL=1250, RR=250, 因后装反相) */
void Servo_Sit(void)
{
    /* 目标: [FL, FR, RL, RR] */
    uint16_t target[4] = {750, 750, 1250, 250};
    int i, done;
    uint8_t step = 10;  /* 每步CCR增量 */

    for (i = 0; i < 80; i++) {
        done = 1;
        for (int ch = 0; ch < 4; ch++) {
            uint16_t cur = g_servoCCR[ch];
            uint16_t tgt = target[ch];
            if (cur < tgt) {
                cur += step; if (cur > tgt) cur = tgt;
                g_servoCCR[ch] = cur; Servo_WriteCCR(ch, cur);
                done = 0;
            } else if (cur > tgt) {
                if (cur < step) cur = 0;
                else cur -= step;
                if (cur < tgt) cur = tgt;
                g_servoCCR[ch] = cur; Servo_WriteCCR(ch, cur);
                done = 0;
            }
        }
        if (done) break;
        delay_ms(12);
    }
}

/* 卧倒/休眠 (阻塞, 一次性动作)
 *   前腿 → 中立位+90° 后弯 (FL=250, FR=1250, FR因前装反相)
 *   后腿 → 中立位+90° 前弯 (RL=1250, RR=250, RR因后装反相) */
void Servo_Sleep(void)
{
    /* 目标: [FL, FR, RL, RR] — 四条腿全部偏离中立90° */
    uint16_t target[4] = {250, 1250, 1250, 250};
    int i, done;
    uint8_t step = 10;  /* 每步CCR增量 */

    for (i = 0; i < 80; i++) {
        done = 1;
        for (int ch = 0; ch < 4; ch++) {
            uint16_t cur = g_servoCCR[ch];
            uint16_t tgt = target[ch];
            if (cur < tgt) {
                cur += step; if (cur > tgt) cur = tgt;
                g_servoCCR[ch] = cur; Servo_WriteCCR(ch, cur);
                done = 0;
            } else if (cur > tgt) {
                if (cur < step) cur = 0;
                else cur -= step;
                if (cur < tgt) cur = tgt;
                g_servoCCR[ch] = cur; Servo_WriteCCR(ch, cur);
                done = 0;
            }
        }
        if (done) break;
        delay_ms(12);
    }
}

/* 停止 (归中) */
void Servo_Stop(void)
{
    Servo_AllMid();
}

/* 跳舞: 四腿依次抬起 */
void Servo_Dance(void)
{
    Servo_SetCCR(0, 550); delay_ms(200);
    Servo_SetCCR(0, SERVO_MID_CCR); delay_ms(100);
    Servo_SetCCR(1, 950); delay_ms(200);
    Servo_SetCCR(1, SERVO_MID_CCR); delay_ms(100);
    Servo_SetCCR(2, 550); delay_ms(200);
    Servo_SetCCR(2, SERVO_MID_CCR); delay_ms(100);
    Servo_SetCCR(3, 950); delay_ms(200);
    Servo_SetCCR(3, SERVO_MID_CCR); delay_ms(100);
}


/*===========================================================================
 * 4. main — 主程序
 *=========================================================================*/
#define LED_ON()   DL_GPIO_clearPins(GPIOA, DL_GPIO_PIN_14)
#define LED_OFF()  DL_GPIO_setPins(GPIOA, DL_GPIO_PIN_14)

typedef enum {
    STATE_IDLE = 0,
    STATE_WALK_FORWARD,
    STATE_WALK_BACKWARD,
    STATE_TURN_LEFT,
    STATE_TURN_RIGHT,
    STATE_SIT,
    STATE_DANCE,
} RobotState;

static RobotState g_state = STATE_IDLE;

/* 防抖: 缓存上次命令ID */
static uint8_t g_lastDisplayedCmd = 0xFF;
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
int main(void)
{
    uint8_t lastResult = 0;

    board_init();

    /* UART1 波特率改为 115200 (syscfg默认9600, MP3模块需要115200) */
    DL_UART_Main_setBaudRateDivisor(UART_1_INST, 2, 11);  // 4MHz→115200

    /* MP3 开机初始化 */
    MP3_SetVolume(10);   // 音量 25/31
    MP3_Stop();       // 确保停止状态

    /* OLED 初始化 (先于舵机, 避免GPIO操作干扰PWM) */
    OLED_Init();
    OLED_Clear(0);
    OLED_Refresh();

    Servo_Init();

    /* 开机自检: 舵机微动一下确认PWM正常 */
    Servo_SetCCR(0, 500);
    Servo_SetCCR(1, 1000);
    delay_ms(300);
    Servo_AllMid();
                //g_state = STATE_WALK_FORWARD;

    printf("\r\n================================\r\n");
    printf(" DMX + CI1302 + OLED + Servo\r\n");
    printf("================================\r\n\r\n");

    /* 开机显示 */
    OLED_DisplayCommand(0x00);   // 显示待机图 (gImage_idle)
    CI1302_Speak(CI1302_ANNOUNCE, 0x01);
    printf("[SYS] Ready.\r\n\r\n");
        //g_state = STATE_WALK_FORWARD;
    while (1) {
        uint8_t result = CI1302_Recognition();
        
        if (result != 0x00 && result != 0x80 && result != lastResult) {
            HandleCommand(result);
            lastResult = result;
        }

        /* 非阻塞步态更新 */
        printf("[DBG] g_state=%d\r\n", g_state);
        if (g_state == STATE_WALK_FORWARD) {
            Servo_GaitUpdate(GAIT_FORWARD, g_gaitStep);
            g_gaitStep = (g_gaitStep + 1) % CYCLE_STEPS;
        } else if (g_state == STATE_WALK_BACKWARD) {
            Servo_GaitUpdate(GAIT_BACKWARD, g_gaitStep);
            g_gaitStep = (g_gaitStep + 1) % CYCLE_STEPS;
        } else if (g_state == STATE_TURN_LEFT) {
            Servo_GaitUpdate(GAIT_TURN_LEFT, g_gaitStep);
            g_gaitStep = (g_gaitStep + 1) % CYCLE_STEPS;
        } else if (g_state == STATE_TURN_RIGHT) {
            Servo_GaitUpdate(GAIT_TURN_RIGHT, g_gaitStep);
            g_gaitStep = (g_gaitStep + 1) % CYCLE_STEPS;
        } else if (g_state == STATE_DANCE) {
            Servo_GaitUpdate(GAIT_DANCE, g_gaitStep);
            g_gaitStep = (g_gaitStep + 1) % CYCLE_STEPS;
        }
        delay_ms(CYCLE_DELAY_MS);
    }
}

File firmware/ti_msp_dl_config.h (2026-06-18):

/*
 * Copyright (c) 2023, Texas Instruments Incorporated - http://www.ti.com
 * All rights reserved.
 *
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
 * *  Redistributions of source code must retain the above copyright
 *    notice, this list of conditions and the following disclaimer.
 *
 * *  Redistributions in binary form must reproduce the above copyright
 *    notice, this list of conditions and the following disclaimer in the
 *    documentation and/or other materials provided with the distribution.
 *
 * *  Neither the name of Texas Instruments Incorporated nor the names of
 *    its contributors may be used to endorse or promote products derived
 *    from this software without specific prior written permission.
 *
 * THIS SOFTWARE IS PROVIDED BY THE COPYRIGHT HOLDERS AND CONTRIBUTORS "AS IS"
 * AND ANY EXPRESS OR IMPLIED WARRANTIES, INCLUDING, BUT NOT LIMITED TO,
 * THE IMPLIED WARRANTIES OF MERCHANTABILITY AND FITNESS FOR A PARTICULAR
 * PURPOSE ARE DISCLAIMED. IN NO EVENT SHALL THE COPYRIGHT OWNER OR
 * CONTRIBUTORS BE LIABLE FOR ANY DIRECT, INDIRECT, INCIDENTAL, SPECIAL,
 * EXEMPLARY, OR CONSEQUENTIAL DAMAGES (INCLUDING, BUT NOT LIMITED TO,
 * PROCUREMENT OF SUBSTITUTE GOODS OR SERVICES; LOSS OF USE, DATA, OR PROFITS;
 * OR BUSINESS INTERRUPTION) HOWEVER CAUSED AND ON ANY THEORY OF LIABILITY,
 * WHETHER IN CONTRACT, STRICT LIABILITY, OR TORT (INCLUDING NEGLIGENCE OR
 * OTHERWISE) ARISING IN ANY WAY OUT OF THE USE OF THIS SOFTWARE,
 * EVEN IF ADVISED OF THE POSSIBILITY OF SUCH DAMAGE.
 */

/*
 *  ============ ti_msp_dl_config.h =============
 *  Configured MSPM0 DriverLib module declarations
 *
 *  DO NOT EDIT - This file is generated for the MSPM0G350X
 *  by the SysConfig tool.
 */
#ifndef ti_msp_dl_config_h
#define ti_msp_dl_config_h

#define CONFIG_MSPM0G350X

#if defined(__ti_version__) || defined(__TI_COMPILER_VERSION__)
#define SYSCONFIG_WEAK __attribute__((weak))
#elif defined(__IAR_SYSTEMS_ICC__)
#define SYSCONFIG_WEAK __weak
#elif defined(__GNUC__)
#define SYSCONFIG_WEAK __attribute__((weak))
#endif

#include <ti/devices/msp/msp.h>
#include <ti/driverlib/driverlib.h>
#include <ti/driverlib/m0p/dl_core.h>

#ifdef __cplusplus
extern "C" {
#endif

/*
 *  ======== SYSCFG_DL_init ========
 *  Perform all required MSP DL initialization
 *
 *  This function should be called once at a point before any use of
 *  MSP DL.
 */


/* clang-format off */

#define POWER_STARTUP_DELAY                                                (16)



#define CPUCLK_FREQ                                                     32000000



/* Defines for PWM_1 */
#define PWM_1_INST                                                         TIMA1
#define PWM_1_INST_IRQHandler                                   TIMA1_IRQHandler
#define PWM_1_INST_INT_IRQN                                     (TIMA1_INT_IRQn)
#define PWM_1_INST_CLK_FREQ                                               500000
/* GPIO defines for channel 0 */
#define GPIO_PWM_1_C0_PORT                                                 GPIOA
#define GPIO_PWM_1_C0_PIN                                         DL_GPIO_PIN_15
#define GPIO_PWM_1_C0_IOMUX                                      (IOMUX_PINCM37)
#define GPIO_PWM_1_C0_IOMUX_FUNC                     IOMUX_PINCM37_PF_TIMA1_CCP0
#define GPIO_PWM_1_C0_IDX                                    DL_TIMER_CC_0_INDEX

/* Defines for PWM_2 */
#define PWM_2_INST                                                         TIMA0
#define PWM_2_INST_IRQHandler                                   TIMA0_IRQHandler
#define PWM_2_INST_INT_IRQN                                     (TIMA0_INT_IRQn)
#define PWM_2_INST_CLK_FREQ                                               500000
/* GPIO defines for channel 0 */
#define GPIO_PWM_2_C0_PORT                                                 GPIOA
#define GPIO_PWM_2_C0_PIN                                          DL_GPIO_PIN_0
#define GPIO_PWM_2_C0_IOMUX                                       (IOMUX_PINCM1)
#define GPIO_PWM_2_C0_IOMUX_FUNC                      IOMUX_PINCM1_PF_TIMA0_CCP0
#define GPIO_PWM_2_C0_IDX                                    DL_TIMER_CC_0_INDEX

/* Defines for PWM_3 */
#define PWM_3_INST                                                        TIMG12
#define PWM_3_INST_IRQHandler                                  TIMG12_IRQHandler
#define PWM_3_INST_INT_IRQN                                    (TIMG12_INT_IRQn)
#define PWM_3_INST_CLK_FREQ                                               500000
/* GPIO defines for channel 0 */
#define GPIO_PWM_3_C0_PORT                                                 GPIOB
#define GPIO_PWM_3_C0_PIN                                         DL_GPIO_PIN_20
#define GPIO_PWM_3_C0_IOMUX                                      (IOMUX_PINCM48)
#define GPIO_PWM_3_C0_IOMUX_FUNC                    IOMUX_PINCM48_PF_TIMG12_CCP0
#define GPIO_PWM_3_C0_IDX                                    DL_TIMER_CC_0_INDEX
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
